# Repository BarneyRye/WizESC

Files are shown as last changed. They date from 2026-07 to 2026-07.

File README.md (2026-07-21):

# WizESC

- Custom STM32G431 sensorless electronic speed controller, running on [**AM32**](https://github.com/am32-firmware/am32) firmware.
- Designed to normally run from a 3S battery supply, and commanded via bi-directional DSHOT-300.

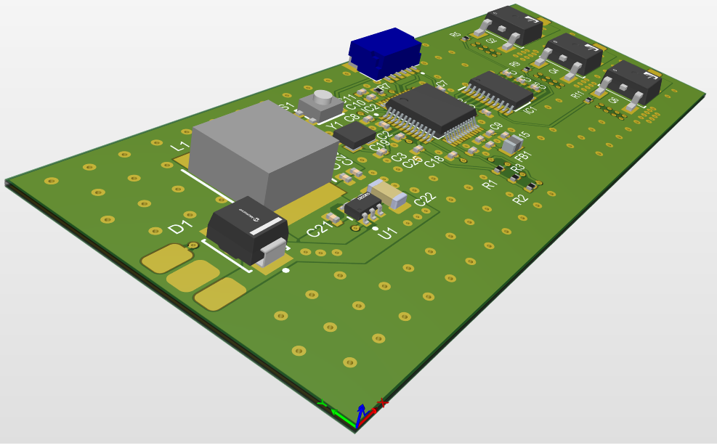
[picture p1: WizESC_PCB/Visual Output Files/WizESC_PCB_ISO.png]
WizESC assembled board, isometric view


> [!WARNING]
> **This board is untested and unverified.** It has been designed and routed in full, and the
> firmware target has been derived against upstream AM32, but it has not been manufactured or
> brought up. Treat everything here as a educational design project rather than a proven product.

---

## Overview

| | |
|---|---|
| **MCU** | STM32G431CBT6 (Cortex-M4F @ 160 MHz, LQFP48) |
| **Gate driver** | TI DRV8300DPWR — 3-phase, bootstrapped high-side |
| **Power stage** | 6 × AOD4184A N-channel MOSFETs (DPAK) |
| **Input voltage** | 3S LiPo nominal (~11.1 V), up to 4S |
| **Commutation** | Sensorless BEMF via the STM32's internal comparators (COMP1/COMP2) |
| **Throttle input** | Bi-directional DSHOT-300 on PB4 (TIM3_CH1) |
| **Current sensing** | None — no shunts fitted |
| **Firmware** | AM32 2.20, stock `g431` target + one custom board target |
| **PCB** | 4-layer, 77.1 × 32.5 mm |
| **EDA tool** | Altium Designer 26.8.1 |

---

## Schematic

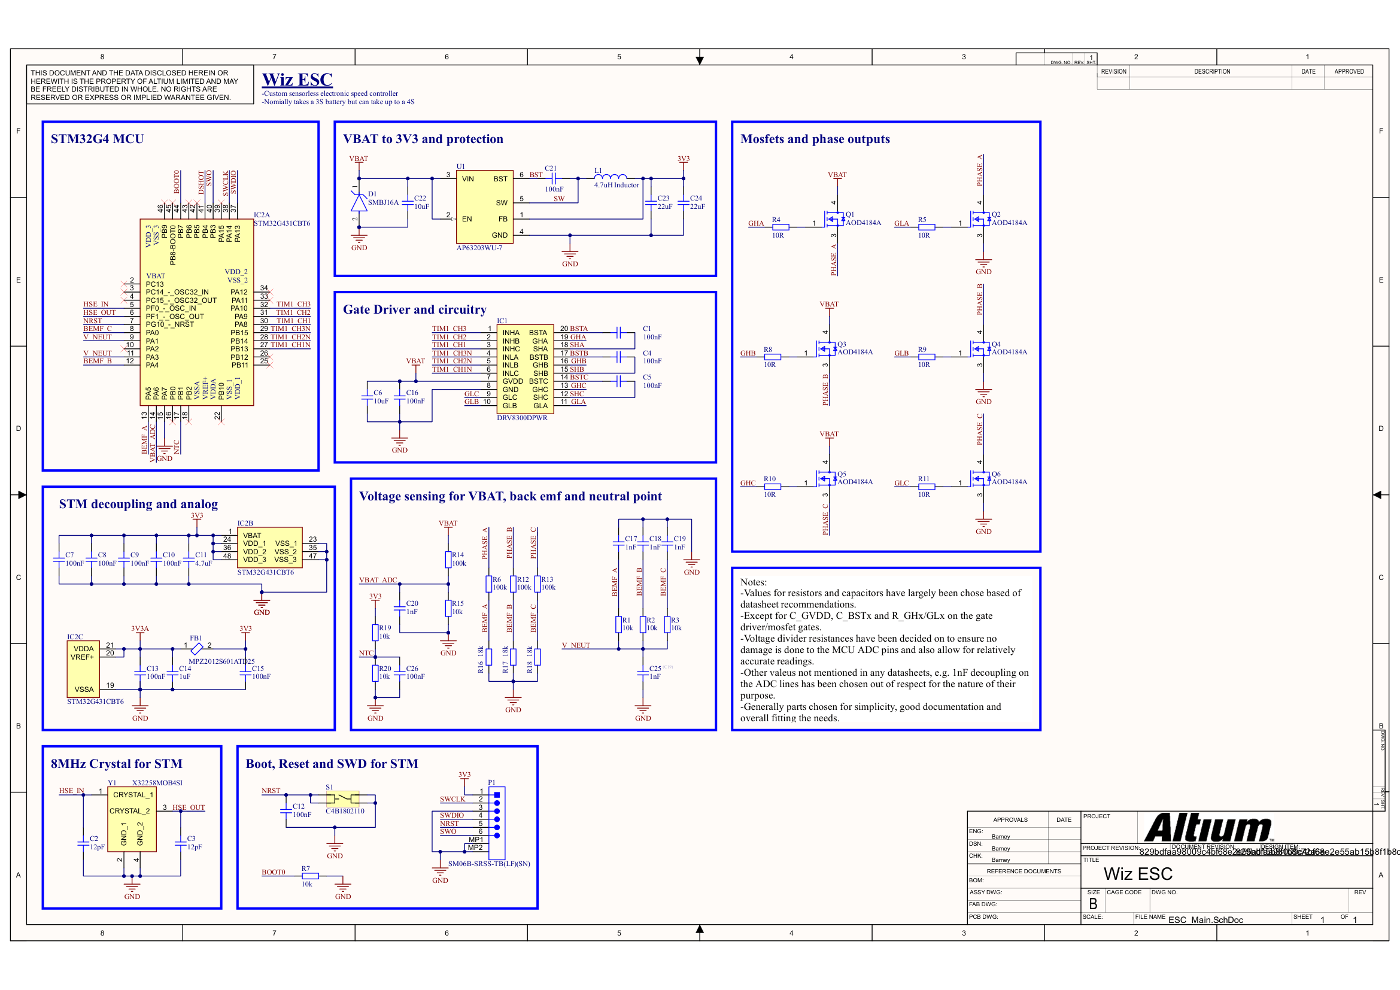
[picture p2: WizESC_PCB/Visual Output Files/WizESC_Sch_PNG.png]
WizESC schematic sheet


Full-resolution PDF: [WizESC_Sch_PDF.pdf](WizESC_PCB/Visual%20Output%20Files/WizESC_Sch_PDF.pdf)

### Power

Battery voltage feeds the power stage directly and is stepped down to 3V3 by an
**AP63203WU-7** synchronous buck (4.7 µH inductor L1, 2 × 22 µF output). An **SMBJ16A** TVS
diode across the input clamps transients. The analogue supply is split off through a ferrite bead with its own decoupling.

### Gate drive

The DRV8300 drives all six FETs from a single 12 V-class GVDD rail derived from VBAT, with a
100 nF bootstrap capacitor per phase and 10 Ω series gate resistors on every gate

Sizing of the bootstrap capacitors, GVDD bulk capacitance and gate resistors is worked through
from the datasheet equations in
[driver-Component-calcs.md](WizESC_PCB/driver-Component-calcs.md).

### Sensing

- **Back-EMF** — each phase is divided 100k:18k into a comparator input, with the virtual
  neutral point formed by a 3 × 10k star and filtered by a 1 nF capacitor. Phase A uses COMP2,
  phases B and C share COMP1.
- **Battery voltage** — 100k:10k divider into PA6 (ADC2_IN3), giving a divider ratio of 11.
- **Temperature** — NTC divider footprint on PB1 (ADC1_IN12). No thermistor is fitted in the
  current BOM, but AM32 requires the pin to be defined.
- **Current** — not implemented. PA7 is tied to GND and `USE_CURRENT_SENSE` is left undefined.

### Debug and control

A 6-way JST **SM06B-SRSS-TB** connector (P1) carries SWD — SWCLK, SWDIO, NRST and SWO plus
power — for ST-LINK bootloader flashing. S1 is a reset button on NRST; BOOT0 is pulled through
R7.

---

## Layout

Top and bottom assembly views:

| Top | Bottom |
|---|---|
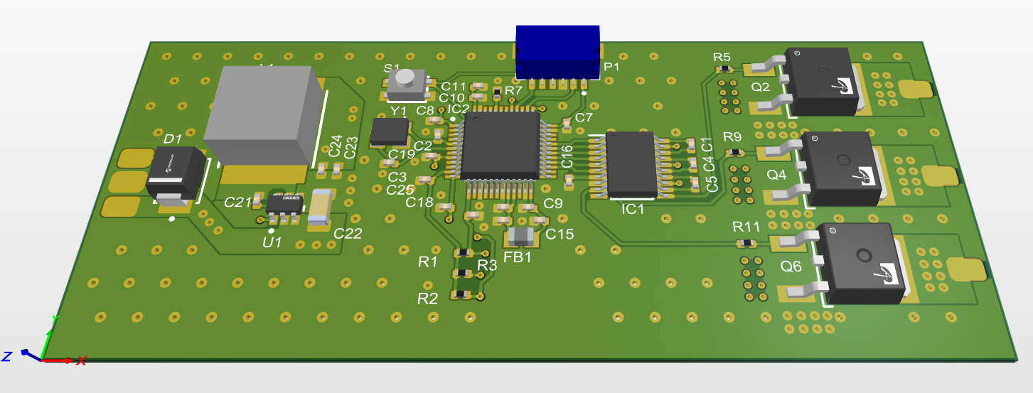
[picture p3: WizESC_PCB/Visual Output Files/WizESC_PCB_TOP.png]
Top side
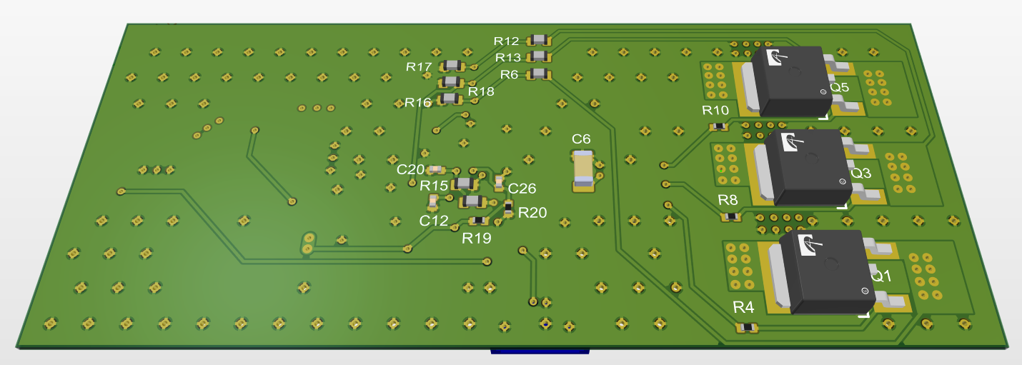
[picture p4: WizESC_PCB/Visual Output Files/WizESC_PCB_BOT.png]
Bottom side
|  |  |

From left to right, sits the input pads, MCU and additional circuitry, then finally the gate driver and mosfets to the output pads.

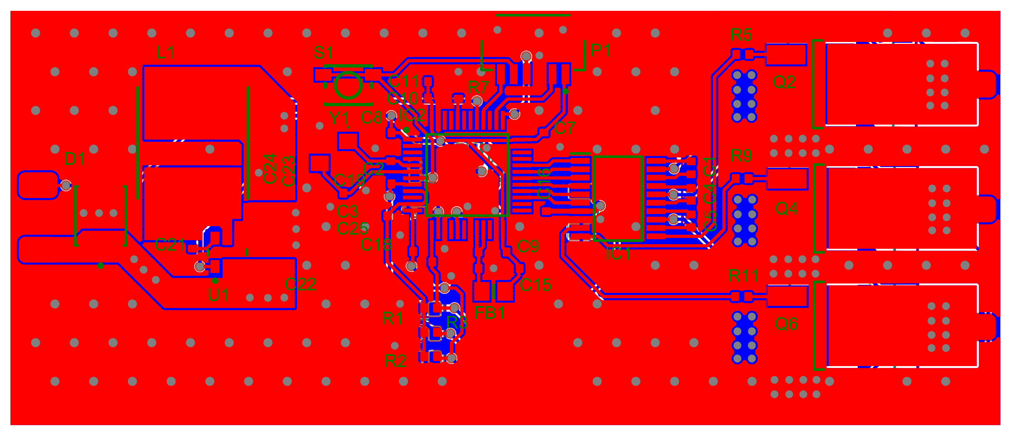
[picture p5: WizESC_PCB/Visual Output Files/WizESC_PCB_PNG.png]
Top layer routing


**Stackup:** 4 layers — Signal/GND/VBAT/Signal, with GND pours and via sticking on both signal planes.

A [3D STEP model](WizESC_PCB/Visual%20Output%20Files/WizESC_PCB_3D.step) and a
[PCB drawing PDF](WizESC_PCB/Visual%20Output%20Files/WizESC_PCB_PDF.pdf) are also included.

---

## Firmware

The board runs **stock AM32** — no motor-control code is modified. Only a board-target entry
(`WIZESC_G431`) is added to `Inc/targets.h`.

Board specific board config can be found in **[FIRMWARE_SETUP.md](FIRMWARE_SETUP.md)**. Note this does not include the full setup, which can be found in the **AM32** installation docs.

AM32 is a separate third-party open-source project (GPL-3.0). This repository is not affiliated
with or endorsed by it and contains none of its source code — only the configuration needed to
build it for this hardware.

---

## Repository layout

```
Custom_ESC/
|--FIRMWARE_SETUP.md                    AM32 board target, pin map, flashing notes
|--WizESC_PCB/
    |-- WizESC_PCB.PrjPcb               Altium project
    |--ESC_Main.SchDoc                  Schematic
    |--ESC_PCB.PcbDoc                   PCB layout
    |--WizESC_PCB.BomDoc                BOM document
    |--ESC_Gerbers_CAM.Cam              Gerber output job
    |--ESC_Drill_CAM.Cam                Drill output job
    |--driver-Component-calcs.md        DRV8300 component calculations
    |--Visual Output Files/             Renders, schematic PNG/PDF, STEP model
    |--Project Outputs for WizESC_PCB/
        |--WizESC_Gerbers.zip           Fabrication package
        |--WizESC_BOM.csv               Bill of materials (LCSC part numbers)
        |--Pick Place for ESC_PCB.csv   Assembly pick-and-place
|--README.md                            This file
```

## Manufacturing

Everything needed for fabrication (with JLCPCB) and assembly is checked in:

- **Gerbers + drill** — `Project Outputs for WizESC_PCB/WizESC_Gerbers.zip`
- **BOM** — `WizESC_BOM.csv`, with LCSC part numbers
- **Pick and place** — `Pick Place for ESC_PCB.csv`

Parts were selected for availability, good documentation and simplicity.

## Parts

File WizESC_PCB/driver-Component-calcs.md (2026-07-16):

# DRV8300 Gate Driver Component Calculations
### MOSFET: AOD4184A | Battery: 3S LiPo | Driver: TI DRV8300DPWR
---
## 0. Datasheets for reference
1. DRV8300DPWR: https://www.ti.com/lit/ds/symlink/drv8300.pdf
2. AD4184A: https://www.aosmd.com/res/datasheets/AOD4184A.pdf

## 1. Design values

| Parameter | Value | Source / Notes |
|---|---|---|
| V_GVDD | 12 V | Average 3S battery |
| f_SW (PWM frequency) | 20 kHz | Assumed - matches TI reference design |
| Q_G (AOD4184A, max @ V_GS=10V) | 33 nC | AOD4184A datasheet (typ 27.2 nC) |
| R_G (AOD4184A internal gate resistance) | 3.5 Ω typ (2-5 Ω range) | AOD4184A datasheet |
| V_BOOTD (bootstrap diode fwd drop, max @ 100µA) | 0.85 V | DRV8300 datasheet, Electrical Characteristics |
| V_BSTUV (falling, max) | 4.5 V | DRV8300 datasheet, Protection Circuits |
| IL_BS_TRANS (bootstrap leakage, transient, max) | 220 µA | DRV8300 datasheet, Electrical Characteristics |
| V_GHx_HI (typ @ 100 mA) | 0.6 V | DRV8300 datasheet - used to derive driver source resistance |
| V_GLx_LO (typ @ 100 mA) | 0.15 V | DRV8300 datasheet - used to derive driver sink resistance |
| Target bootstrap ripple, ΔV | 1 V | Standard design target (TI recommends 0.5-1 V) |

---

## 2. Bootstrap Capacitor (C_bstx)

**Step 1 — Available voltage headroom (Eq. 2, DRV8300 datasheet):**

```
ΔV_BSTx(avail) = V_GVDD − V_BOOTD − V_BSTUV
               = 12 − 0.85 − 4.5
               = 6.65 V
```

**Step 2 — Total charge per switching cycle (Eq. 3):**

```
Q_TOT = Q_G + (IL_BS_TRANS / f_SW)
      = 33 nC + (220 µA / 20 kHz)
      = 33 nC + 11 nC
      = 44 nC
```

**Step 3 — Minimum bootstrap capacitor (Eq. 4):**

```
C_BST(min) = Q_TOT / ΔV
           = 44 nC / 1 V
           = 44 nF
```

**C_BSTx value: 100 nF** </br>
*Chosen as the DRV8300 recommends giving headroom, and 100nF is a common value, and matches the datasheet*

---

## 3. GVDD Capacitor (C_GVDD)

**10× rule (Eq. 5, DRV8300 datasheet):**

```
C_GVDD ≥ 10 × C_BST
       = 10 × 100 nF
       = 1 µF (by this rule alone)
```

**However**, the DRV8300 pin-function table 6-2, specifies for at least a **10uF** capacitor for C_GVDD, so that has been selected. </br>
In addition I will add a single 100nF capacitor for the faster transients

---

## 4. Gate Resistors (R_GHx / R_GLx)

**Driver internal resistance, derived from electrical characteristics (@ 100 mA test current, V_GVDD = 12V):**

```
R_driver(source) = V_GHx_HI / 0.1 A = 0.6 / 0.1 = 6 Ω
R_driver(sink)   = V_GLx_LO / 0.1 A = 0.15 / 0.1 = 1.5 Ω
```

**Sizing for target peak turn-on current (~600 mA, under 750 mA typ / 1200 mA max source rating):**

```
R_ext = V_GVDD / I_peak_target − R_driver − R_G(FET)
      = 12 / 0.6 − 6 − 3.5
      = 20 − 9.5
      ≈ 10 Ω
```

**Check turn-off (sink path) with same resistor:**

```
I_peak(off) = V_GVDD / (R_ext + R_driver_sink + R_G)
            = 12 / (10 + 1.5 + 3.5)
            = 12 / 15
            = 800 mA
```
(Comfortably under 1500 mA typ / 2100 mA max sink rating.)

---

## 5. Summary Table

| Component | Calculated Min | Selected Value | Notes |
|---|---|---|---|
| C_GVDD (bulk) | 1 µF | **10 µF** ceramic (X5R/X7R) | Datasheet pin spec mandates ≥10 µF, overrides 10× rule |
| C_GVDD (HF decoupling) | — | **100 nF** ceramic | Placed at GVDD/GND pins, in addition to bulk cap |
| C_BSTx (per phase) | 44 nF | **100 nF** ceramic | Placed close to BSTx-SHx pins |
| R_GHx (high-side) | ~10 Ω | **10 Ω** | Peak source ≈600 mA @ 10 Ω |
| R_GLx (low-side) | ~10 Ω | **10 Ω**  | Peak sink ≈800 mA @ 10 Ω |

***N.B. On part selection capacitor ratings and resistor power dissipation ratings should be considered***

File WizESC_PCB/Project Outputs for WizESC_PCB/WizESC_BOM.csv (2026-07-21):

Rating | LCSC | Manufacturer Part Number | Manufacturer | Name | Designator | Quantity
50V X7R, 25V X5R | C960916, C100072 | CL05B104KB5NNNC, CL05A104KA5NNNC | Samsung Electro-Mechanics | 100nF | C1, C4, C5, C7, C8, C9, C10, C12, C13, C15, C16, C21, C26 | 13
50V C0G | C26406 | CL05C120JB5NNNC | Samsung Electro-Mechanics | 12pF | C2, C3 | 2
X7S | C2803389 | CL31Y106KBKVPNE | Samsung Electro-Mechanics | 10uF | C6, C22 | 2
10V X5R | C368809 | CL05A475KP5NRNC | Samsung Electro-Mechanics | 4.7uF | C11 | 1
25V X5R | C52923 | CL05A105KA5NQNC | Samsung Electro-Mechanics | 1uF | C14 | 1
50V X7R | C14442 | CL05B102KB5NNNC | Samsung Electro-Mechanics | 1nF | C17, C18, C19, C20, C25 | 5
16V X5R | C2762594 | CL10A226MO7JZNC | Samsung Electro-Mechanics | 22uF | C23, C24 | 2
 | C353386 | SMBJ16A | Jingdao Microelectronics | MSMBJ16AE3 | D1 | 1
 | C81034 | MPZ2012S601ATD25 | TDK | MPZ2012S601ATD25 | FB1 | 1
 | C3036056 | DRV8300DPWR | Texas Instruments | DRV8300DPWR | IC1 | 1
 | C529355 | STM32G431CBT6TR | STMicroelectronics | STM32G431CBT6 | IC2 | 1
 | C266436 | SMNR8040-4R7MT | Shun Xiang Nuo | 4.7uH Inductor | L1 | 1
 | C160405 | SM06B-SRSS-TB(LF)(SN) | JST | SM06B-SRSS-TB(LF)(SN) | P1 | 1
 | [NoParam], C99124 | [NoParam], AOD4184A | [NoParam], AOS | AOD4184A | Q1, Q2, Q3, Q4, Q5, Q6 | 6
 | C2906861 | FRC0402F1002TS | FOJAN | 10k | R1, R2, R3, R7, R19, R20 | 6
 | C2906862 | FRC0402F10R0TS | FOJAN | 10R | R4, R5, R8, R9, R10, R11 | 6
 | C2907088 | FRC0603J104 TS | FOJAN | 100k | R6, R12, R13, R14 | 4
 | C2906982 | FRC0603F1002TS | FOJAN | 10k | R15 | 1
 | C2907001 | FRC0603F1802TS | FOJAN | 18k | R16, R17, R18 | 3
 | C49393608 | C4B1802110 | SAMZO | C4B1802110 | S1 | 1
 | C780769 | AP63203WU-7 | Diodes Inc. | AP63203WU-7 | U1 | 1
 | C2682775 | X32258MOB4SI | YXC | X32258MOB4SI | Y1 | 1

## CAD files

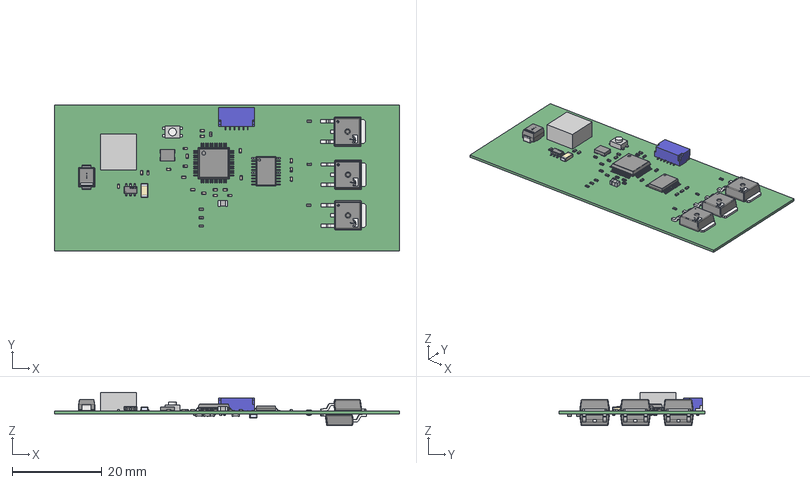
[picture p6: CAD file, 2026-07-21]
WizESC_PCB/Visual Output Files/WizESC_PCB_3D.step
77.1 x 32.5 x 7.42 mm
R0402 x 12
C0402 x 24
Pins
pins
logo
Extruded x 5
R0603 x 8
Alpha & Omega Logo x 6
SM06B-SRSS-TB
PinsArrayLR x 2
PinsArrayTB
term1
term2
direction _Mark
Microchip
C1206 x 2
INDUCTOR

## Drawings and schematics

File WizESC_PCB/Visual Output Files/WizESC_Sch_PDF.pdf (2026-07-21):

REVISION | DESCRIPTION | DATE | APPROVED | REV. SHT. DWG. NO. 1

# 3V3 SWCLK SWDIO SWO DSHOT

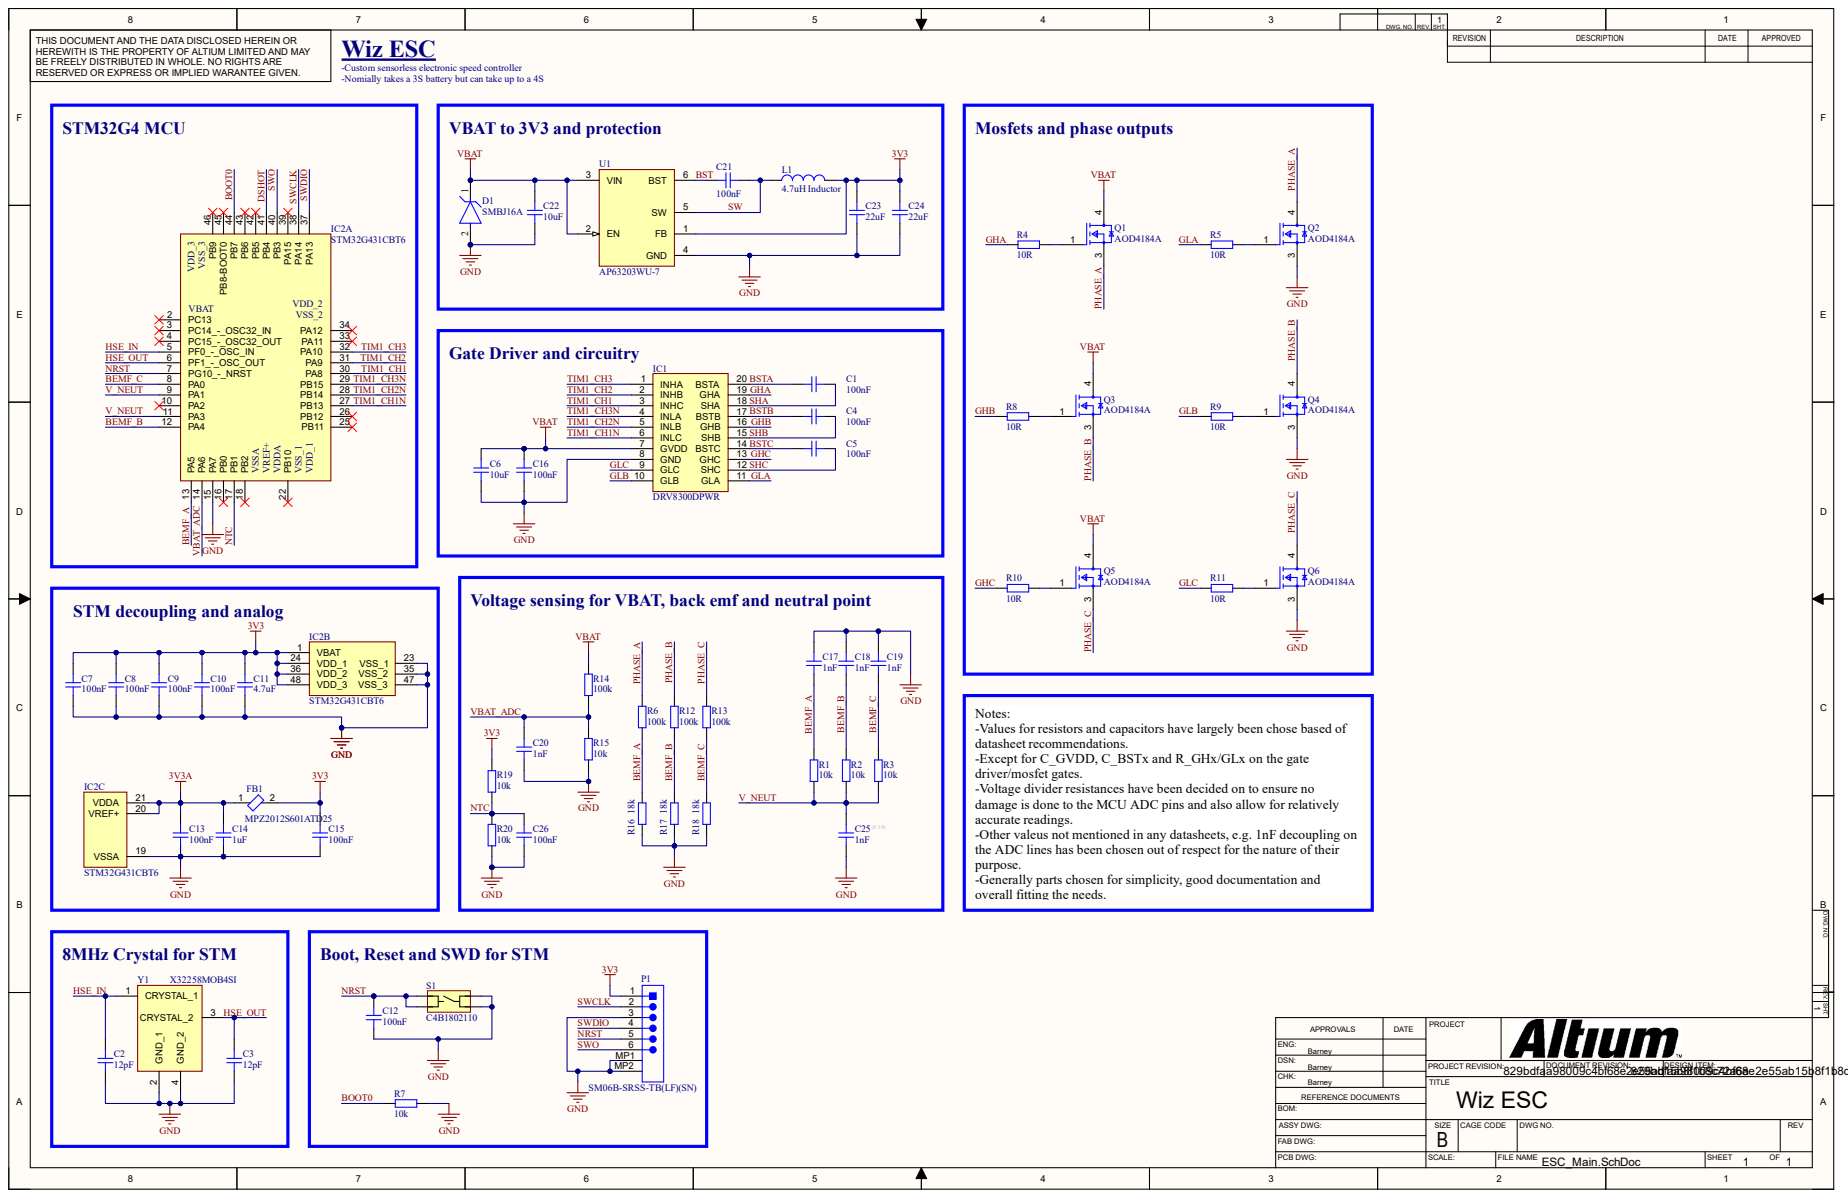
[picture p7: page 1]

DWG. NO. | REV. | 1 SHT.

THIS DOCUMENT AND THE DATA DISCLOSED HEREIN OR HEREWITH IS THE PROPERTY OF ALTIUM LIMITED AND MAY BE FREELY DISTRIBUTED IN WHOLE. NO RIGHTS ARE RESERVED OR EXPRESS OR IMPLIED WARANTEE GIVEN. | Wiz ESC

-Custom sensorless electronic speed controller
-Nomially takes a 3S battery but can take up to a 4S

VBAT to 3V3 and protection

Mosfets and phase outputs

Gate Driver and circuitry

STM decoupling and analog

Voltage sensing for VBAT, back emf and neutral point

Notes:
-Values for resistors and capacitors have largely been chose based of
datasheet recommendations.
-Except for C_GVDD, C_BSTx and R_GHx/GLx on the gate
driver/mosfet gates.
-Voltage divider resistances have been decided on to ensure no
damage is done to the MCU ADC pins and also allow for relatively
accurate readings.
-Other valeus not mentioned in any datasheets, e.g. 1nF decoupling on
the ADC lines has been chosen out of respect for the nature of their
purpose.
-Generally parts chosen for simplicity, good documentation and
overall fitting the needs.

DSN: Barney
CHK: Barney

SM06B-SRSS-TB(LF)(SN)

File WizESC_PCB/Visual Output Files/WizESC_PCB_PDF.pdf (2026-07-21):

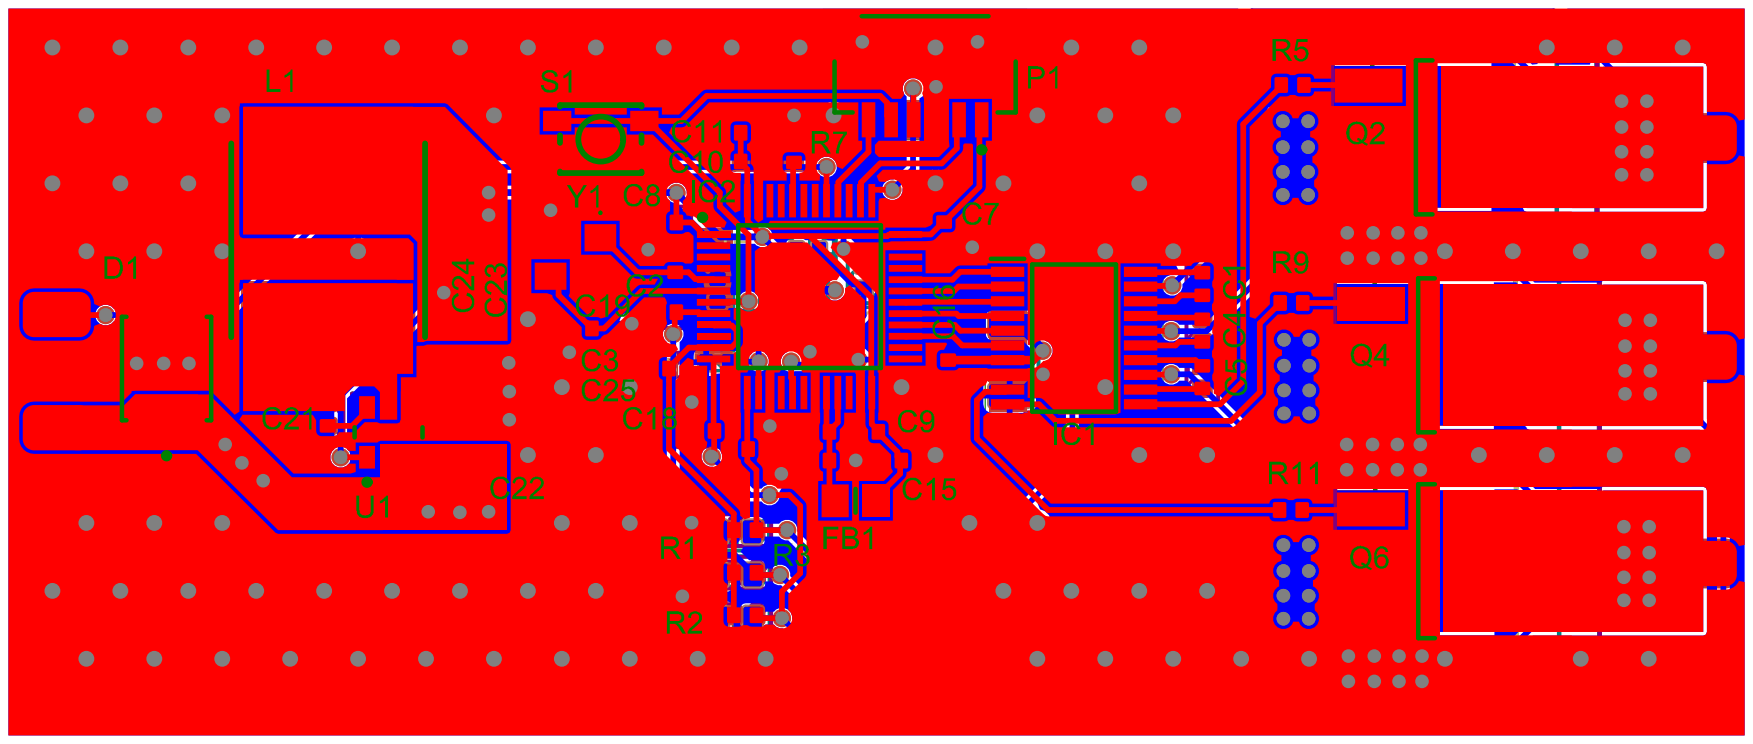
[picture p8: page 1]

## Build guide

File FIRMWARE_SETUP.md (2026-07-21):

# WizESC — Firmware Configuration

This board runs on **AM32**, using its stock `g431` target plus one custom board-target
entry. No motor-control code is modified.

This document only covers modification of the current **AM32** setup, not the whole proccess.

### Attribution

AM32 is a separate third-party open-source project, licensed **GPL-3.0**, maintained at
<https://github.com/am32-firmware/AM32>.

This repository is **not affiliated with, endorsed by, or connected to** the AM32 project
or its maintainers. It contains no AM32 source code — only the board-specific
configuration required to build AM32 for this hardware. All credit for the firmware
belongs to its authors. Refer to the upstream repository for the toolchain, build
instructions, flashing procedure and licence terms.

Configuration below was derived against upstream commit `ad91453` (2026-07-09),
firmware version **2.20**.

---

## Board target

Target name: **`WIZESC_G431`**

Add to `Inc/targets.h`, alongside the other `*_G431` entries:

```c
#ifdef WIZESC_G431
#define FIRMWARE_NAME "WIZESC_G431 "
#define FILE_NAME "WIZESC_G431"
#define DEAD_TIME 80 // 500 ns @ 160 MHz TIM1
#define HARDWARE_GROUP_G4_D
#define TARGET_STALL_PROTECTION_INTERVAL 20000
#define TARGET_VOLTAGE_DIVIDER 110 // R14:R15 = 100k:10k -> ratio 11

#define USE_ADC_1_2
#define VOLTAGE_ADC_PIN LL_GPIO_PIN_6 // PA6 = ADC2_IN3
#define VOLTAGE_ADC_CHANNEL LL_ADC_CHANNEL_3
#define NTC_ADC_PIN LL_GPIO_PIN_1 // PB1 = ADC1_IN12
#define NTC_ADC_CHANNEL LL_ADC_CHANNEL_12
#define CURRENT_ADC_PIN LL_GPIO_PIN_7 // PA7 tied to GND, no shunt fitted
#define CURRENT_ADC_CHANNEL LL_ADC_CHANNEL_4
#define MILLIVOLT_PER_AMP 1 // placeholder; USE_CURRENT_SENSE is NOT defined

#define USE_HSE
#undef HSE_VALUE
#define HSE_VALUE 8000000 // 8 MHz crystal, Y1
#define USE_HSE_BYPASS 0
#endif
```

Two constraints worth knowing:

- **`FILE_NAME` must keep the `_G431` suffix.** Targets are discovered by grepping this
  file for `define FILE_NAME` lines containing the MCU suffix, so renaming it removes the
  build target entirely.
- **`FIRMWARE_NAME` must be exactly 12 characters** (pad with spaces) — it goes into a
  fixed-width field reported to the configurator.

Build target is then `WIZESC_G431`; artefacts are named `AM32_WIZESC_G431_2.20.bin/.hex`.

---

## Where the constants come from

| Macro | Value | Derivation |
|---|---|---|
| `HARDWARE_GROUP_G4_D` | — | The only G431 hardware group whose PWM pins match this board exactly: PA10/PB15, PA9/PB14, PA8/PB13 |
| `TARGET_VOLTAGE_DIVIDER` | 110 | `battery_voltage` is held in centivolts (cell count is derived by dividing by 370, i.e. 3.70 V/cell), and the conversion computes `mV × DIVIDER/100`. The macro is therefore **10 × the true divider ratio**. R14:R15 = 100k:10k → ratio 11 → **110** |
| `DEAD_TIME` | 80 | SYSCLK is 160 MHz (HSE 8 MHz, PLL M=1 N=40 R=2). TIM1 runs `Prescaler=0`, `CLOCKDIVISION_DIV1` → 6.25 ns/tick. 80 × 6.25 ns = **500 ns**. |
| `USE_ADC_1_2` | set | Not optional. In the single-ADC path, `VOLTAGE_ADC_PIN` is initialised on GPIOA and read on ADC1 — but ADC1's only GPIOA channels are PA0–PA3, all consumed here by the comparators and throttle. VBAT must go via ADC2 on PA6 |
| `NTC_*` / `CURRENT_*` | set | The `USE_ADC_1_2` path references both unconditionally, and `MILLIVOLT_PER_AMP` is referenced unguarded in the current-conversion maths. Omitting any of them is a compile error, regardless of whether the hardware is fitted |
| `USE_CURRENT_SENSE` | **not defined** | This is the "no current sensing" sentinel. This board has no shunts — leave it undefined and disable current limiting in the configurator |

---

## Pin map

| Pin | Port | Net | Function |
|---|---|---|---|
| 8 | PA0 | BEMF_C | COMP1_INM (IO2) — phase C sense |
| 9 | PA1 | V_NEUT | COMP1_INP (IO1) — virtual neutral |
| 11 | PA3 | V_NEUT | COMP2_INP (IO2) — virtual neutral |
| 12 | PA4 | BEMF_B | COMP1_INM (IO1) — phase B sense |
| 13 | PA5 | BEMF_A | COMP2_INM (IO1) — phase A sense |
| 14 | PA6 | VBAT_ADC | ADC2_IN3 — battery voltage |
| 15 | PA7 | GND | ADC2_IN4 — sampled but unused, no shunt |
| 17 | PB1 | NTC | ADC1_IN12 — board temperature |
| 27 | PB13 | TIM1_CH1N | phase C low |
| 28 | PB14 | TIM1_CH2N | phase B low |
| 29 | PB15 | TIM1_CH3N | phase A low |
| 30 | PA8 | TIM1_CH1 | phase C high |
| 31 | PA9 | TIM1_CH2 | phase B high |
| 32 | PA10 | TIM1_CH3 | phase A high |
| 37 / 38 | PA13 / PA14 | SWDIO / SWCLK | debug header P1 |
| 41 | PB4 | DSHOT | TIM3_CH1 — throttle input |

### Comparator scheme

| Phase | COMP | Minus (phase) | Plus (neutral) | EXTI |
|---|---|---|---|---|
| A | COMP2 | PA5 | PA3 | 22 |
| B | COMP1 | PA4 | PA1 | 21 |
| C | COMP1 | PA0 | PA1 | 21 |

---

## Board-specific flashing notes

Procedure can be found in the **AM32** docs, only board specific constants are defined in this documents

- Bootloader is flashed once via **ST-LINK over SWD** (header P1). AM32 bootloaders are
  named by throttle input pin — this board uses **PB4**.
- Application address: **`0x08001000`**
- Settings EEPROM: **`0x0800F800`** — a full chip erase resets configuration.

---

## Notes

Currently, this board is untested and unverified, as I have been unable to manufacture it due to personal constraints.

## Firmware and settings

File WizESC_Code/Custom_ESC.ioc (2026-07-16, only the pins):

Mcu.UserName=STM32G474CBTx
PA0.GPIO_Label=VBAT_ADC
PA0.Signal=ADC1_IN1
PA1.GPIO_Label=BEMF_A
PA1.Signal=ADC1_IN2
PA10.Signal=S_TIM1_CH3
PA13.Signal=SYS_JTMS-SWDIO
PA14.Signal=SYS_JTCK-SWCLK
PA2.GPIO_Label=BEMF_B
PA2.Signal=ADC1_IN3
PA3.GPIO_Label=BEMB_C
PA3.Signal=ADC1_IN4
PA8.Signal=S_TIM1_CH1
PA9.Signal=S_TIM1_CH2
PB0.GPIO_Label=V_NEUT
PB0.Signal=ADC1_IN15
PB13.Signal=TIM1_CH1N
PB14.Signal=TIM1_CH2N
PB15.Signal=TIM1_CH3N
PB3.Signal=SYS_JTDO-SWO
PB4.GPIO_Label=DSHOT
PB4.Signal=S_TIM3_CH1
PF0-OSC_IN.Signal=RCC_OSC_IN
PF1-OSC_OUT.Signal=RCC_OSC_OUT

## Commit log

2026-05-15 Folder layout change
    [Custom_ESC.PrjPcb, ESC_Main.SchDoc]
2026-07-14 Changed from KiCAD to altium
    [ESC_Main.SchDoc, WizESC_PCB.PrjPcb]
2026-07-16 Finished schematic, moving onto PCB
    [ESC_Main.SchDoc, WizESC_PCB.PrjPcb]
2026-07-17 Added design rules and initial main component placement
    [ESC_PCB.PcbDoc, WizESC_PCB.PrjPcb]
2026-07-19 Finished up PCB/Sch
    [ESC_Main.SchDoc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]
2026-07-21 Removed code, replacing with am32, and updated sch/pcb for am32 software
    [ESC_Main.SchDoc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]
2026-07-21 Finished up README.md and firmware setup notes for AM32
    [ESC_Main.SchDoc, ESC_PCB.PcbDoc]
2026-07-21 Fix to gerbers and sch pdf/png
    [ESC_Main.SchDoc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]
